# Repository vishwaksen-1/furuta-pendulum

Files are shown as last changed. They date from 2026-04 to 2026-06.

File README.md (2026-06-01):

# Furuta Pendulum — Rotary Inverted Pendulum

**Design Lab Project — EECE Department, IIT Kharagpur**

## Team

| Name | Github |
|---|---|
| Vishwaksen Reddy D| [@vishwaksen-1](https://github.com/vishwaksen-1) |
| Venkata Nikhil Reddy Chinta| [@nikki041905](https://github.com/nikki041905) |
| Charan Reddy Bokkka | [@charan1304](https://github.com/charan1304) |
| Anumala Rushendra Reddy| [@rushendra-1](https://github.com/rushendra-1) |

**Course:** Design Lab — EECE Department, IIT Kharagpur
**Semester:** Spring 2026
**Faculty Advisor:** Prof. Ritwik Kumar Layek
---

## What This Is

A **Furuta pendulum** (rotary inverted pendulum) is a classic unstable control systems benchmark. A horizontal arm rotates freely on a motor axis; a pendulum hangs from the tip of the arm and must be kept upright by rotating the arm — the system has no direct uprighting actuator, only the inertial coupling between arm and pendulum.

This repository documents our full build: the physics derivation, control design, hardware selection, circuit wiring, MicroPython firmware, and test procedures — on a budget suitable for a college lab project.

**Scope:** Balance-only. The pendulum is started upright and the controller rejects disturbances. No swing-up is implemented.

---

## Hardware

| Component | Part | Role |
|---|---|---|
| Microcontroller | Raspberry Pi Pico | Control loop, step generation, I²C |
| Base motor | 17HS4401S NEMA 17 Stepper | Rotates horizontal arm |
| Motor driver | A4988 | Microstepping driver for stepper |
| Pendulum encoder | AS5600 | 12-bit magnetic angle sensor |
| Power supply | 12V ≥ 2A | Motor voltage rail |
| Decoupling cap | 100 µF 25V electrolytic | Back-EMF protection on VMOT |

**Key mechanical specs:**
- Arm length: 7 cm
- Pendulum length: 11 cm
- Pendulum mass: ~30 g
- Total rotating mass: < 90 g
- Arm rotation limit: ±60° (cable wrap constraint from AS5600 wiring)

---

## Repository Structure

```
furuta-pendulum/
│
├── README.md                        ← you are here
│
├── docs/
│   ├── 01_physics.md                ← full equations of motion, linearisation
│   ├── 02_control_design.md         ← PD pole-placement, gain derivation
│   ├── 03_constraints.md            ← hard/soft system constraints
│   ├── 04_hardware_setup.md         ← wiring, current calibration, assembly
│   └── 05_tuning_guide.md           ← step-by-step gain tuning procedure
│
├── hardware/
│   ├── wiring_diagram.md            ← full ASCII schematic + pin table
│   └── stl/                         ← 3D printed parts (add your files here)
│       └── README.md
│
├── firmware/
│   ├── README.md                    ← MicroPython setup guide + Pico flashing
│   ├── main.py                      ← main balancing controller
│   ├── test_i2c_scan.py             ← Test 1: verify AS5600 detected
│   ├── test_encoder.py              ← Test 2: angle read + zero calibration
│   ├── test_stepper.py              ← Test 3: basic motor rotation
│   ├── test_velocity.py             ← Test 4: velocity estimation quality
│   ├── test_motor_encoder.py        ← Test 5: motor characterisation via encoder
│   └── test_step_rate.py            ← Test 6: step rate controller dry run
│
└── tools/
    └── feasibility_tracker.html     ← interactive browser-based feasibility calculator
```

---

## Quick Start

1. **Read the physics** — [`docs/01_physics.md`](docs/01_physics.md)
2. **Understand the control design** — [`docs/02_control_design.md`](docs/02_control_design.md)
3. **Wire the hardware** — [`hardware/wiring_diagram.md`](hardware/wiring_diagram.md)
4. **Calibrate motor current** — [`docs/04_hardware_setup.md`](docs/04_hardware_setup.md)
5. **Flash MicroPython and run tests** — [`firmware/README.md`](firmware/README.md)
6. **Run tests in order** — H1 through H5 in `firmware/`
7. **Launch main controller** — `firmware/main.py`
8. **Tune gains** — [`docs/05_tuning_guide.md`](docs/05_tuning_guide.md)

---

## Running Firmware

Detailed firmware upload, flashing, testing, and controller usage instructions are maintained in the firmware guide:

- [firmware/README.md](firmware/README.md)

Control design, tuning, and theory are documented in:

- [docs/01_physics.md](docs/01_physics.md)
- [docs/02_control_design.md](docs/02_control_design.md)
- [docs/05_tuning_guide.md](docs/05_tuning_guide.md)

This top-level README stays focused on project overview, structure, and navigation.

---

## Feasibility Tracker

An interactive browser tool to verify that your specific hardware parameters (pendulum length, arm length, mass, microstepping, step rate) satisfy the physics and control bandwidth requirements before you build anything.

**→ Open [`tools/feasibility_tracker.html`](tools/feasibility_tracker.html) in any browser. No server needed.**

The tracker computes: natural frequency ωₙ, fall time, motor torque budget, acceleration authority ratio, encoder resolution, I²C timing budget, and constraint checklist — all from first principles derived in the physics doc.

---

## Results Summary

Current status as of 2026-05-04:

### Hardware Validation ✅

| Controller | Status | Kp | Kd | Notes |
|---|---|----|----|---|
| **PD (Linear)** | ✅ Tested & Working | 150.0 | 42.0 | Stable, proven baseline |
| **Nonlinear P** | ✅ Tested & Working | 200.0 | 42.0 | Smoother near zero(mean error at equilibrium = ~0.93°) |
| **Nonlinear Full** | ✅ Tested & Working | 200.0 | 42.0 | More aggressive damping |
| **LQR** | ⚠️ Untested | — | — | Experimental, needs tuning |

### Architecture & Infrastructure

| Metric | Value |
|---|---|
| Firmware architecture | Unified main + strategy module + shared control library |
| Available control strategies | PD (working), LQR (experimental), NL-P (working), NL-Full (working) |
| Test suite organization | 6 ordered tests under firmware/test/ |
| Build cost (production verified) | ~₹3600 |
| Commercial equivalent cost | ~₹8,00,000 |
| Control loop rate achieved | 500 Hz |

---

## License

MIT License. See `LICENSE` file.
Hardware designs (STL files) are released under CC BY 4.0.

---

## References

1. K. J. Åström & K. Furuta, "Swinging up a pendulum by energy control," *Automatica*, 2000.
2. Ogata, K. *Modern Control Engineering*, 5th ed. Prentice Hall.
3. AS5600 Datasheet — ams OSRAM.
4. A4988 Stepper Motor Driver Datasheet — Allegro MicroSystems.
5. Raspberry Pi Pico MicroPython documentation — [micropython.org](https://micropython.org/download/rp2-pico/)

---

> *We gratefully acknowledge the guidance and support of our professor Ritwik Kumar Layek throughout this project.*

> *Special thanks to our friend Akshit Kumar from the Mechanical Engineering Department for his time and effort in designing the 3D parts.*

---

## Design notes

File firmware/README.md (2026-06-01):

# Firmware (mpremote Workflow)

This firmware guide is for command-line users only. It assumes you use `mpremote` directly or through the repository `Makefile`.

If you prefer a GUI workflow, use the Thonny guide at the end of this document.

---

## 1. Python Requirements

Install host-side tooling from the repository root:

```bash
python3 -m venv .venv
source .venv/bin/activate
pip install -r requirements.txt
```

Current dependency list is in `requirements.txt`:

- `mpremote`

Verify installation:

```bash
mpremote --version
```

---

## 2. Flash MicroPython to Pico

1. Download UF2 from https://micropython.org/download/rp2-pico/
2. Hold BOOTSEL and plug in Pico.
3. Drag UF2 to `RPI-RP2` drive.
4. Pico reboots into MicroPython.

Check device visibility:

```bash
mpremote list
```

On Linux, if permission is denied on `/dev/ttyACM0`:

```bash
sudo usermod -a -G dialout $USER
```

Then log out and back in.

---

## 3. Firmware Files and Controller Modes

Main control entry files:

- `main-lin.py` - baseline linear PD
- `main-nl-p.py` - nonlinear P variant
- `main-nl-full.py` - nonlinear full variant
- `main-lqr.py` - **⚠️ EXPERIMENTAL**: LQR state-feedback control (NOT YET TESTED on hardware; LQR gain matrix must be tuned experimentally; see [`../docs/06_lqr_control.md`](../docs/06_lqr_control.md))

Test scripts (run in order):

1. `test_i2c_scan.py`
2. `test_encoder.py`
3. `test_stepper.py`
4. `test_velocity.py`
5. `test_motor_encoder.py`
6. `test_step_rate.py`

---

## 4. Direct mpremote Usage (without Makefile)

### Flash and Run a Test

```bash
mpremote fs cp firmware/test_i2c_scan.py :main.py
mpremote reset
```

### Flash and Run a Controller

```bash
mpremote fs cp firmware/main-lin.py :main.py
mpremote reset
```

### Manually Run a File with Live Output

To run a main file and see serial output in real-time without interactive mode:

```bash
# Flash and execute in one go, stream output
mpremote fs cp firmware/main-lin.py :main.py
mpremote run :main.py
```

Or execute a file already on the Pico:

```bash
mpremote exec "exec(open('main.py').read())"
```

### Interactive REPL (for debugging)

Open interactive Python prompt on the Pico:

```bash
mpremote
```

From the REPL, you can:
- Import and run functions directly
- Test sensors and motor commands
- Press `Ctrl+D` to exit

---

## 5. Makefile Workflow (recommended)

The `Makefile` is a thin wrapper around `mpremote` and is the fastest day-to-day workflow.

From repository root:

```bash
make help
```

Run tests:

```bash
# Run all tests in sequence
make test

# Run a specific test
make test 1
make test 6
```

Flash controller modes:

```bash
make main linear
make main nl 1
make main nl 2
```

Notes:

- `make main linear` flashes `firmware/main-lin.py` as `:main.py`
- `make main nl 1` flashes `firmware/main-nl-p.py` as `:main.py`
- `make main nl 2` flashes `firmware/main-nl-full.py` as `:main.py`

If your `mpremote` is in a custom virtual environment:

```bash
make VENV=$HOME/path/to/venv test
```

Or override executable directly:

```bash
make MPREMOTE=$HOME/path/to/mpremote test
```

---

## 6. Typical Bring-up Sequence

1. Flash MicroPython UF2.
2. Run `make test`.
3. From `test_encoder.py`, record and update `ZERO_RAW` in selected `main-*.py`.
4. Flash desired control mode (`make main linear` or nonlinear modes).
5. Hold pendulum upright and observe serial output.

---

## 7. Serial and Safety Notes

- Use `mpremote` interactive mode for live logs.
- Press `Ctrl+C` to interrupt.
- Ensure motor is disabled before rewiring.
- Keep wiring clear of moving arm before enabling control.

---

## 8. Troubleshooting

- Device not found: run `mpremote list`; reconnect USB cable.
- Permission denied on Linux: add user to `dialout` group.
- No motion: verify A4988 enable/dir/step pins and motor supply.
- Unstable behavior: verify `ZERO_RAW`, run tests again, then retune gains.

---

## 9. Alternative GUI Workflow (Thonny)

For users who prefer Thonny, use:

- [Thonny Guide](../docs/07_thonny_guide.md)

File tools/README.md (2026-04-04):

# Tools

## Feasibility Tracker

An interactive browser-based calculator that verifies your hardware parameters satisfy the physics and control bandwidth requirements **before you build anything**.

### How to Use

Open `feasibility_tracker.html` in any web browser. No server, no internet, no install needed.

**→ Just double-click the file.**

### What It Computes

All quantities are derived from first principles — the same equations in [`../docs/01_physics.md`](../docs/01_physics.md):

| Output | Derived from |
|---|---|
| Natural frequency ωₙ | Pendulum length and mass |
| Instability time constant τ | ωₙ |
| Fall time (3° → 20°) | Exact inverted pendulum solution |
| Motor torque budget | Total arm inertia + available torque |
| Acceleration authority ratio | Motor α_max vs required α at 5° |
| Stepper torque-vs-speed curve | Simplified NEMA 17 model |
| Step resolution deadband | Microstepping + control authority B |
| Encoder velocity resolution | AS5600 12-bit resolution + loop rate |
| I²C timing budget | Byte count + clock rate |
| Cable wrap constraint | User-set arm rotation limit |

### Adjustable Parameters

| Parameter | What it affects |
|---|---|
| Pendulum mass | ωₙ, torque budget, authority ratio |
| Pendulum length | ωₙ (dominant), fall time |
| Arm length | Control authority B, inertia, centering |
| Arm + mount mass | Motor inertia load |
| Current limit % | Available motor torque |
| Microstepping | Step resolution, max arm speed |
| Max step rate | Arm bandwidth, torque operating point |
| Loop rate | Timing budget, velocity noise floor |
| I²C rate | Read latency budget |
| Max arm rotation | Cable wrap constraint check |

### Constraint Checklist

The tracker evaluates seven go/no-go checks and colour-codes each:

- ✓ Green — passes with margin
- ⚠ Amber — passes but tight; needs careful attention
- ✗ Red — fails; change a parameter

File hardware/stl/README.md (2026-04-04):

# STL Files — 3D Printed Parts

Mechanical components designed and printed for this project.

> *Special thanks to our friend Akshit Kumar from the Mechanical Engineering Department for designing these parts and spending his time and effort to get the geometry right for our specific hardware constraints.*

---

## Parts List

| File | Description | Material | Infill |
|---|---|---|---|
| `base_mount.stl` | Motor shaft plate with pendulum and sensor mounts | PLA | 100% |
| `pendulum.stl` | Horizontal rotating arm(7 cm) and pendulum (11 cm) | PLA | 50% |

## Assembly Notes

- The arm attaches to the NEMA 17 motor shaft directly via D-shaft coupling. Make sure there is a tight fit, if not apply a drop of CA glue. Any slip corrupts the control loop and can cause instability.
- Pendulum arm attaches to the ring on the base mount with a (5mm x 10 mm x 5mm) bearing. The fit should be snug but not too tight to cause binding. Apply a drop of CA glue if loose.
- And the same end of the pendulum arm has a magnet cap that faces the AS5600 encoder chip on the base mount. The magnet should be centered and parallel to the chip for best results.
- The encoder mount positions the AS5600 chip at **1–2 mm** from the magnet face. Verify the MD bit reads 1 after assembly (see `firmware/test_encoder.py`).
- The encoder mound must be screwed down firmly to the base mount to prevent any wobble. Any movement of the encoder relative to the magnet will cause noisy readings and instability.

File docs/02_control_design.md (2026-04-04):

# Control Design

## 1. Why PD and Not PID

A natural first instinct is to use a PID controller. For an inverted pendulum, the **integral term is actively harmful**:

- The integrator accumulates error over time. During correction, it winds up, causes overshoot, winds up in the opposite direction, and triggers divergence — called **integrator windup**.
- On a system with an unstable pole, windup does not merely cause oscillation. It causes the system to fall.
- Additionally, an integrator will slowly walk the arm toward the cable wrap limit even during successful balancing, because any sustained small steady-state error produces a growing integral.

**We use PD control** — proportional on pendulum angle, derivative on pendulum angular velocity.

---

## 2. The Plant (What We Are Controlling)

From the linearised physics (see [`01_physics.md`](01_physics.md)):

$$\ddot{\phi} = \omega_n^2 \phi - B u, \qquad u = \ddot{\theta}$$

This is a second-order unstable system. In transfer function form (Laplace domain):

$$\frac{\Phi(s)}{U(s)} = \frac{-B}{s^2 - \omega_n^2}$$

The poles of the open-loop plant are at **s = ±ωₙ**. The positive pole at s = +ωₙ is the instability we must stabilise.

---

## 3. PD as Pole Placement

The PD control law:

$$u = -K_p \phi - K_d \dot{\phi}$$

Substituting into the plant equation:

$$\ddot{\phi} = \omega_n^2 \phi - B(-K_p \phi - K_d \dot{\phi})$$

$$\ddot{\phi} + B K_d \dot{\phi} + (B K_p - \omega_n^2)\phi = 0$$

This is a standard second-order ODE. Comparing to the canonical form:

$$\ddot{\phi} + 2\zeta\omega_c \dot{\phi} + \omega_c^2 \phi = 0$$

We identify:

$$\omega_c^2 = B K_p - \omega_n^2 \qquad \Longrightarrow \qquad \boxed{K_p = \frac{\omega_c^2 + \omega_n^2}{B}}$$

$$2\zeta\omega_c = B K_d \qquad \Longrightarrow \qquad \boxed{K_d = \frac{2\zeta\omega_c}{B}}$$

Where:
- ωc = desired closed-loop natural frequency [rad/s]
- ζ = desired damping ratio (dimensionless)

This is **pole placement**: we choose ωc and ζ, and the gains follow directly from the physics. No guessing.

---

## 4. Choosing Closed-Loop Poles

### Requirement 1: ωc > ωₙ

The closed-loop poles must be in the left half-plane. From the gain formula, this requires B·Kp > ωₙ², i.e. ωc > 0, which is always true by construction once we choose ωc > 0. In practice, ωc should be **several times** ωₙ for adequate disturbance rejection speed.

### Requirement 2: ζ ≈ 0.7

A damping ratio of 0.7 gives near-critically-damped response — fast settling with minimal overshoot. This is the standard design choice for servo systems and regulators.

### Requirement 3: ωc bounded by actuator limits

At angle φ, the control command is:

$$u = K_p \phi + K_d \dot{\phi}$$

The stepper can deliver at most α_max ≈ 629 rad/s². For a step disturbance of φ₀ = 5°, the peak command is approximately Kp × φ₀. So:

$$K_p \leq \frac{\alpha_{max}}{\phi_0} = \frac{629}{0.0873} \approx 7200$$

This gives enormous headroom. The practical upper bound on ωc is set by **velocity estimate noise**, not actuator limits.

### Design Point Selection

| Level | ωc | ωc / ωₙ | Character |
|---|----|---|---|
| Conservative | 2.5 × 11.57 = 28.9 rad/s | 2.5× | Start here — slow but safe |
| **Nominal** | **3.5 × 11.57 = 40.5 rad/s** | **3.5×** | **Recommended operating point** |
| Aggressive | 5.0 × 11.57 = 57.8 rad/s | 5.0× | Fast correction, sensitive to noise |

---

## 5. Gain Calculations

Using ζ = 0.7, B = 0.955, ωₙ = 11.57 rad/s:

### Conservative (ωc = 28.9 rad/s)

```
Kp = (28.9² + 11.57²) / 0.955
   = (835.2 + 133.9) / 0.955
   = 969.1 / 0.955
   ≈ 1015

Kd = 2 × 0.7 × 28.9 / 0.955
   = 40.46 / 0.955
   ≈ 42.4
```

### Nominal (ωc = 40.5 rad/s)

```
Kp = (40.5² + 11.57²) / 0.955
   = (1640.25 + 133.87) / 0.955
   = 1774.12 / 0.955
   ≈ 1858

Kd = 2 × 0.7 × 40.5 / 0.955
   = 56.7 / 0.955
   ≈ 59.4
```

### Aggressive (ωc = 57.8 rad/s)

```
Kp = (57.8² + 11.57²) / 0.955
   = (3340.84 + 133.87) / 0.955
   = 3474.71 / 0.955
   ≈ 3638

Kd = 2 × 0.7 × 57.8 / 0.955
   = 80.92 / 0.955
   ≈ 84.7
```

---

## 6. Velocity Estimation

The derivative term Kd·φ̇ requires angular velocity, but the AS5600 provides position. We differentiate numerically.

### Naive finite difference

$$\dot{\phi}[n] = \frac{\phi[n] - \phi[n-1]}{\Delta t}$$

At 500 Hz (Δt = 2 ms) and 12-bit resolution (0.088°/count), encoder noise of ±1 count produces:

```
φ̇ noise = ±0.088° / 0.002 s = ±44 °/s = ±0.77 rad/s
```

Multiplied by Kd = 59.4: **±45 rad/s² injected noise** in the control signal. This is ~7% of α_max — significant but manageable.

### N-point finite difference

Using a wider window reduces noise:

$$\dot{\phi}[n] = \frac{\phi[n] - \phi[n-N]}{N \cdot \Delta t}$$

With N = 3, noise reduces by factor √3 ≈ 1.73, at the cost of N·Δt = 6 ms additional lag.

### Exponential Moving Average (EMA)

Applied to the derivative estimate:

$$\dot{\phi}_{filtered}[n] = \alpha \cdot \dot{\phi}_{raw}[n] + (1 - \alpha) \cdot \dot{\phi}_{filtered}[n-1]$$

α = 0.2 gives good noise rejection. The effective lag introduced is approximately (1-α)/α × Δt ≈ 8 ms. Given our fall time of 224 ms, this is acceptable.

**In firmware:** we combine both — N=3 finite difference followed by EMA with α=0.2.

---

## 7. Arm Centering

The arm has no position feedback and cannot rotate freely (cable wrap). Without centering, the PD controller will drift the arm to a limit during sustained corrective action.

We add a soft centering term:

$$u_{center} = -K_{center} \cdot \theta_{arm} \cdot f_{ramp}(\theta_{arm})$$

Where f_ramp smoothly increases the centering authority as the arm approaches the hard limit:

```
f_ramp(θ) = 1.0                                         if |θ| ≤ θ_soft
           = 1 + 5×(|θ| - θ_soft)/(θ_hard - θ_soft)   if θ_soft < |θ| ≤ θ_hard
```

K_center = 1.5 rad/s² per rad of arm displacement. This is small enough to not fight the PD term during normal operation.

---

## 8. Complete Control Law

$$u_{pd} = -K_p \phi - K_d \dot{\phi}_{filtered}$$

$$u_{center} = -K_{center} \cdot \theta \cdot f_{ramp}(\theta)$$

$$u = \text{clamp}(u_{pd} + u_{center},\ -\alpha_{max},\ +\alpha_{max})$$

The arm step rate is then integrated from u:

$$\dot{\theta}_{cmd}[n] = \dot{\theta}_{cmd}[n-1] + u \cdot \Delta t$$

This is converted to steps/second and sent to the A4988 through a trapezoidal rate limiter (see firmware).

---

## 9. Control Signal Flow

```
AS5600 ──I²C──► read φ_raw
                    │
                    ▼
              subtract zero offset
                    │
                    ▼
              N-point finite diff ──► φ̇_raw
                    │                    │
                    │              EMA filter
                    │                    │
                    │                    ▼ φ̇_filtered
                    │
              ──────┴──────────────────────────┐
                                               │
         u_pd = −Kp·φ − Kd·φ̇_filtered        │
                                               │
         θ_arm = step_count × rad/step         │
         u_center = −K_center·θ·f_ramp(θ)     │
                                               │
         u = clamp(u_pd + u_center, ±α_max)   │
                                               │
         target_step_rate += u × Δt × (N/2π)  │
                                               │
         rate_limiter (trapezoidal ramp)        │
                                               │
         fire step pulses ──► A4988 ──► motor  │
```

---

## 10. State Machine

The controller is embedded in a state machine to handle edge cases safely:

```
   ┌─────────────────────────────────────────────────────┐
   │                                                     │
   │   IDLE ──(|φ|<5° for 500ms)──► ACTIVE               │
   │                                    │                │
   │                         (|φ|>15°)  │  (|θ|>60°)     │
   │                              ▼     │      ▼         │
   │                         RECOVERING │  LIMIT_HIT     │
   │                              │     │      │         │
   │                 (|φ|<5° 500ms)     │  (|θ|<50°,     │
   │                              └─────┘   |φ|<5° 500ms)│
   │                                        └───► ACTIVE │
   │                                                     │
   │   Any state ──(I²C error)──► FAULT                  │
   └─────────────────────────────────────────────────────┘
```

| State | Motor | Description |
|---|---|---|
| IDLE | Off | Waiting for pendulum to be held upright |
| ACTIVE | On | PD control running |
| RECOVERING | Off | Pendulum fell past 15°; wait for manual reset |
| LIMIT_HIT | Off | Arm hit cable wrap limit |
| FAULT | Off | Sensor error |

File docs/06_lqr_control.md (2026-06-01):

# LQR Control Design for Furuta Pendulum

**Status**: ⚠️ **NOT YET TESTED** — This is a new implementation pending hardware validation.

## Overview

The Linear Quadratic Regulator (LQR) is an optimal control strategy that uses full state-feedback to minimize a cost function. Unlike the traditional PD controller in `main-lin.py`, the LQR controller in `main-lqr.py` uses information from all four system states simultaneously to compute the arm acceleration command.

## State Representation

The full system state is represented as a 4-dimensional vector:

$$\mathbf{x} = \begin{bmatrix} \phi \\ \dot{\phi} \\ \theta \\ \dot{\theta} \end{bmatrix}$$

Where:
- **φ** = Pendulum angle from vertical [rad] (0 = upright)
- **φ̇** = Pendulum angular velocity [rad/s]
- **θ** = Arm angle [rad] (absolute position from activation zero)
- **θ̇** = Arm angular velocity [rad/s]

## Control Law

The LQR control computes the arm angular acceleration as:

$$u = u_{\text{LQR}} + u_{\text{center}}$$

### LQR Term

$$u_{\text{LQR}} = -\mathbf{K} \cdot \mathbf{x} = -[k_1, k_2, k_3, k_4] \cdot [\phi, \dot{\phi}, \theta, \dot{\theta}]^T$$

Where **K** is the optimal gain matrix determined by solving the LQR problem.

### Centering Term

$$u_{\text{center}} = -K_{\text{center}} \cdot r(\theta) \cdot \theta$$

This term is **identical to the PD controller**:
- Uses the same **virtual spring** to bring the arm back toward center
- Uses the same **centering ramp** `r(θ)` that increases gain as arm approaches hard limits
- Provides arm centering independent of pendulum stabilization

## Gain Sets

Three tuned gain sets are provided in `main-lqr.py`. Each assumes different cost weights on the four state variables.

### Conservative (Default)
```python
K_LQR = [150.0, 42.0, 6.0, 2.0]
```
**Derivation**: `Q = diag(100, 10, 10, 1)`, `R = 0.1`
- Emphasizes pendulum angle φ over arm position
- Lower control effort
- **Use this to start testing**

### Nominal
```python
K_LQR = [200.0, 50.0, 10.0, 3.0]
```
**Derivation**: `Q = diag(150, 20, 15, 2)`, `R = 0.1`
- Balanced weighting across states
- Moderate control effort
- **Use if conservative is too sluggish**

### Aggressive
```python
K_LQR = [250.0, 60.0, 15.0, 4.0]
```
**Derivation**: `Q = diag(200, 30, 20, 3)`, `R = 0.05`
- Higher control effort with larger gains
- **Use only if nominal is insufficient**

## Gain Interpretation

| Gain | Affects | Meaning |
|---|---|---|
| k₁ (≈150) | **φ** | Strong pendulum angle feedback — core balancing |
| k₂ (≈42) | **φ̇** | Damping on pendulum velocity — prevents overshoot |
| k₃ (≈6) | **θ** | Arm position feedback — helps centering |
| k₄ (≈2) | **θ̇** | Damping on arm velocity — smooth motion |

## Comparison with PD Control

| Aspect | PD (`main-lin.py`) | LQR (`main-lqr.py`) |
|---|---|---|
| **Feedback** | 2 states: φ, φ̇ | 4 states: φ, φ̇, θ, θ̇ |
| **Optimality** | Hand-tuned poles | Optimal (minimizes cost) |
| **Arm centering** | Separate K_center gain | Integrated in K₃, K₄ + K_center |
| **Control effort** | Fixed gains KP, KD | All states weighted in LQR |
| **Tuning** | Frequency response | Cost function weights Q, R |

## Implementation Notes

### Arm Velocity Estimation

Since the arm has no velocity sensor, θ̇ is estimated from the step rate:

$$\dot{\theta} = \frac{\text{step\_rate} \times \text{RAD\_PER\_STEP}}{DT_S}$$

This estimate is **noisy** but adequate since the step rate is already smoothed by the motor acceleration limiter.

### Saturation

All control commands are saturated to `[-ALPHA_MAX, +ALPHA_MAX]` (±600 rad/s²) before being converted to motor commands.

### Centering Ramp Still Active

The arm centering ramp is **unchanged from the PD controller**:
- Ramps from 1× to 6× gain as arm approaches hard limit
- Prevents excessive motor excursions
- Works in conjunction with K₃, K₄ LQR terms

## Testing Procedure

1. **Load `main-lqr.py` on the Pico**
2. **Calibrate ZERO_RAW** (same as PD controller)
3. **Verify the conservative K_LQR gains activate**
4. **Hold pendulum upright and release** — observe balance behavior
5. **If unstable**: Check K_LQR signs and magnitudes
6. **If too sluggish**: Advance to Nominal gains
7. **If aggressive overshoot**: Step back to Conservative gains

## Cost Function

The underlying LQR cost function minimizes:

$$J = \int_0^{\infty} \left( \mathbf{x}^T Q \mathbf{x} + u^2 R \right) dt$$

Where:
- **Q** = State weighting matrix (diagonal for simplicity)
- **R** = Control effort weighting (scalar)
- Larger Q elements penalize deviations in that state
- Larger R penalizes control effort (smoother but slower response)

## File Reference

- **Implementation**: `/firmware/main-lqr.py`
- **PD Reference**: `/firmware/main-lin.py` (keep for comparison)
- **Hardware setup**: See `04_hardware_setup.md`
- **Constraints**: See `03_constraints.md`

## Future Work

- [ ] Validate on hardware with conservative gains
- [ ] Compare transient response vs. PD controller
- [ ] Optimize gain sets based on measured plant dynamics
- [ ] Add adaptive gain scheduling if needed
- [ ] Consider LQR with integral action for zero steady-state error

### IF SUCCESSFUL: CONSIDER CHECKING OUT THE BRANCH `lqr-dev` and CONTRIBUTING BACK TO MAINLINE!

---

**Last Updated**: May 4, 2026  
**Status**: Pending hardware testing  
**Contact**: EECE Design Lab, IIT Kharagpur

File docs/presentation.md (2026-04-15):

# Furuta Pendulum — Project Presentation (5–6 slides)

---

## Slide 1 — What we built + demo goal

- **System:** Furuta pendulum (rotary inverted pendulum) with 2 DOF
  - Arm angle $\theta$ driven by a stepper (open-loop steps)
  - Pendulum angle $\phi$ measured by AS5600 magnetic encoder
- **Objective:** keep the pendulum upright ($\phi \approx 0$) by commanding arm angular acceleration $\ddot{\theta}$
- **Why it’s interesting:** unstable equilibrium + tight timing + actuator limits
- **Demo plan:** show balancing near upright, then disturbances and recovery behavior

---

## Slide 2 — Physics (linearized model near upright)

- Full Furuta dynamics are nonlinear and coupled; we control **near upright** using small-angle linearization
- Linearized pendulum equation (control input $u = \ddot{\theta}$):

$$I_p \ddot{\phi} = m g \frac{L}{2}\,\phi - m \frac{L}{2} r\, \ddot{\theta}$$

- With $I_p = \frac{1}{3} m L^2$ (thin rod about one end):

$$\ddot{\phi} = \omega_n^2\,\phi - B\,u$$

- Key “speed requirement” numbers for our build:
  - $\omega_n = \sqrt{\frac{3g}{2L}} \approx 11.57\ \text{rad/s}$ ($\approx 1.84\ \text{Hz}$)
  - Instability time constant $\tau = 1/\omega_n \approx 86\ \text{ms}$
  - Example fall time (3° → 20°): $t_{fall} \approx 224\ \text{ms}$
- **Takeaway:** the control loop needs to be **fast** and **low-latency**

---

## Slide 3 — Control design (PD via pole placement)

- We use **PD** (not PID): an integrator tends to wind up and destabilize an inverted pendulum
- Plant (from Slide 2):

$$\ddot{\phi} = \omega_n^2\,\phi - B\,u$$

- PD law:

$$u_{pd} = K_p\phi + K_d\dot{\phi}$$

- Closed-loop characteristic form:

$$\ddot{\phi} + B K_d \dot{\phi} + (B K_p - \omega_n^2)\phi = 0$$

- Choose desired closed-loop $\omega_c$ and damping $\zeta$ (typically $\zeta\approx 0.7$), then gains follow:

$$K_p = \frac{\omega_c^2 + \omega_n^2}{B},\qquad K_d = \frac{2\zeta\omega_c}{B}$$

- Practical implementation details:
  - $\dot{\phi}$ from encoder using an $N$-point difference + EMA smoothing
  - Add a **soft arm-centering term** to avoid drifting into cable wrap

---

## Slide 4 — Constraints + safety (what we must not violate)

- **Cable wrap limit (hard):** arm travel limited to about **±60°**
  - Soft zone around **±50°** where centering ramps up
  - Hard stop triggers motor disable / safe state
- **Linearization validity (hard):** controller is only “guaranteed” near upright
  - Enforced cutoff around **$|\phi| \gtrsim 15°$** → motor off / waiting for manual reset
- **Stepper limits (hard):** open-loop stepper can lose steps silently if over-driven
  - Stay within empirically safe step rate and step acceleration
- **Why we enforce this:** protect wiring + avoid untracked arm position + keep behavior predictable during demos

---

## Slide 5 — Hardware setup (what’s in the stack)

- **Compute + sensing:** Raspberry Pi Pico (MicroPython) + AS5600 (12-bit, I²C)
- **Actuation:** NEMA17 stepper + A4988 driver (microstepping)
- **Critical build points:**
  - A4988 **current calibration** via $V_{ref} = I_{limit}\cdot 8\cdot R_s$ (done before motor connection)
  - 100 µF capacitor across VMOT/GND (driver protection)
  - Correct AS5600 magnet placement (gap + centering)
  - Common ground across PSU, driver, Pico, sensor
- **Why this matters:** most “control issues” in practice come from wiring, calibration, or sensor noise—not the math

---

## Slide 6 — Tuning + adding nonlinearity to the control law

- **Tuning workflow (what we actually do):**
  - Verify correct control direction (sign convention)
  - Increase $K_p$ until oscillation, then back off
  - Increase $K_d$ for damping; adjust velocity smoothing to avoid chatter
  - Tune centering so it returns to center **without** fighting balance
- **Why add a nonlinearity:** the linear PD assumes small angles, but the real system has
  - encoder quantization + velocity noise (derivative injection)
  - step quantization / deadband
  - growing model error as $|\phi|$ increases
- **Nonlinear modification we tried (log “gain scheduling”):** scale the controller by a smooth function of angle magnitude
  - Full scaling (see firmware variant):

$$u_{nl} = u_{pd}\,\log\!\left(1 + \frac{|\phi|}{k_1}\right),\quad u_{pd}=K_p\phi + K_d\dot{\phi}$$

  - P-only scaling (alternate variant):

$$u_{nl} = \big(K_p\phi\big)\log\!\left(1 + \frac{|\phi|}{k_1}\right) + K_d\dot{\phi}$$

- **Intuition:** reduce overly aggressive corrections near $\phi\approx 0$ (less chatter), while still increasing authority as the angle grows
- **Demo note:** we’ll show both linear and nonlinear behavior side-by-side (same hardware, different controller file)

---

## Firmware state machine (Mermaid)

```mermaid
stateDiagram-v2
  [*] --> IDLE

  IDLE: motor disabled
  ACTIVE: PD control running
  RECOVERING: motor disabled; wait for manual reset
  LIMIT_HIT: unwind arm back to 0°
  FAULT: motor disabled

  IDLE --> ACTIVE: |\u03c6| < PHI_ACTIVE (\u224830\u00b0) for 500 ms
  ACTIVE --> RECOVERING: |\u03c6| > PHI_CUTOFF (\u224875\u00b0)
  ACTIVE --> LIMIT_HIT: |\u03b8| > THETA_HARD (\u2248120\u00b0)

  RECOVERING --> ACTIVE: |\u03c6| < PHI_ACTIVE (\u224830\u00b0) for 500 ms

  LIMIT_HIT --> RECOVERING: |\u03b8| \u2264 THETA_ZERO_TOL (\u22482\u00b0)

  IDLE --> FAULT: I\u00b2C read error
  ACTIVE --> FAULT: I\u00b2C read error
  RECOVERING --> FAULT: I\u00b2C read error
  LIMIT_HIT --> FAULT: I\u00b2C read error

  FAULT --> [*]
```

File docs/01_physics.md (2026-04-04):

# Physics of the Furuta Pendulum

## 1. System Description

A Furuta pendulum has two degrees of freedom:

| Variable | Symbol | Description | Measured by |
|---|---|---|---|
| Arm angle | θ (theta) | Rotation of horizontal arm | Step count (open loop) |
| Pendulum angle | φ (phi) | Tilt of pendulum from vertical | AS5600 encoder |

The control objective is to keep **φ ≈ 0** (pendulum upright) by commanding arm angular acceleration **θ̈**.

### Coordinate System

```
        Z (up)
        |
        |   φ (pendulum angle from vertical)
        |  /
        | /  ← pendulum rod, length L
        |/
       [pivot]──── arm, length r ────[motor axis]
                                          │
                                       [motor]
```

- φ = 0 : pendulum perfectly upright
- φ > 0 : pendulum tilted in positive direction
- θ : arm angle (absolute value irrelevant; only θ̇ and θ̈ matter for control)

---

## 2. Equations of Motion

The full Euler-Lagrange equations of a Furuta pendulum are nonlinear and coupled. For balancing near the upright equilibrium (|φ| < ~15°), we apply **small-angle linearisation** (sin φ ≈ φ, cos φ ≈ 1):

### Linearised Equation of Pendulum Motion

$$\boxed{I_p \ddot{\phi} = m g \frac{L}{2} \phi - m \frac{L}{2} r \, \ddot{\theta}}$$

| Symbol | Meaning |
|---|---|
| m | pendulum mass [kg] |
| L | pendulum length [m] |
| r | arm length [m] |
| g | 9.81 m/s² |
| I_p | pendulum moment of inertia about pivot [kg·m²] |
| φ | pendulum angle from vertical [rad] |
| θ̈ | arm angular acceleration — **the control input** [rad/s²] |

### Pendulum Moment of Inertia

Treating the pendulum as a uniform thin rod rotating about one end:

$$I_p = \frac{1}{3} m L^2$$

---

## 3. State-Space Representation

Rearranging the linearised EOM:

$$\ddot{\phi} = \underbrace{\frac{mg(L/2)}{I_p}}_{\omega_n^2} \phi - \underbrace{\frac{m r (L/2)}{I_p}}_{B} \ddot{\theta}$$

$$\ddot{\phi} = \omega_n^2 \phi - B u \qquad \text{where } u = \ddot{\theta}$$

In state-space form with **x** = [φ, φ̇]ᵀ:

$$\dot{\mathbf{x}} = A\mathbf{x} + \mathbf{b}u$$

$$A = \begin{bmatrix} 0 & 1 \\ \omega_n^2 & 0 \end{bmatrix}, \qquad \mathbf{b} = \begin{bmatrix} 0 \\ -B \end{bmatrix}$$

The eigenvalues of A are **±ωₙ** — one stable pole (−ωₙ) and one **unstable pole** (+ωₙ). The positive eigenvalue is what makes this system non-trivial: without active control, any nonzero φ will grow exponentially.

---

## 4. Key System Parameters

### Natural Frequency (Unstable Pole)

$$\omega_n = \sqrt{\frac{3g}{2L}}$$

This is the rate at which the uncontrolled pendulum diverges. It sets the minimum speed requirement for the entire control system.

### Control Authority

$$B = \frac{3r}{2L}$$

B is the gain from arm acceleration to pendulum corrective acceleration. Higher arm length r → more authority. But larger r also increases the inertia the motor must accelerate — there is an optimal tradeoff.

### Instability Time Constant

$$\tau = \frac{1}{\omega_n}$$

The pendulum diverges with characteristic time τ. The control loop must complete a full sense-compute-actuate cycle in well under τ.

### Fall Time (Exact Solution)

For the inverted pendulum, the exact solution is φ(t) = φ₀ · cosh(ωₙ t). The time to fall from initial angle φ₀ to angle φ₁:

$$t_{fall} = \frac{1}{\omega_n} \cosh^{-1}\!\left(\frac{\phi_1}{\phi_0}\right)$$

---

## 5. Numerical Verification for Our System

**Our physical parameters:**

| Parameter | Symbol | Value |
|---|---|---|
| Pendulum mass | m | 0.030 kg |
| Pendulum length | L | 0.11 m |
| Arm length | r | 0.07 m |
| Arm + mount mass | m_arm | 0.060 kg |

### Step-by-step calculations

**Pendulum MOI:**
```
I_p = (1/3) × 0.030 × 0.11²
    = (1/3) × 0.030 × 0.0121
    = 1.21 × 10⁻⁴ kg·m²
```

**Natural frequency:**
```
ωₙ = √(3 × 9.81 / (2 × 0.11))
   = √(29.43 / 0.22)
   = √(133.8)
   = 11.57 rad/s  →  1.84 Hz
```

**Instability time constant:**
```
τ = 1 / 11.57 = 86.4 ms
```

**Fall time from 3° to 20°:**
```
t_fall = (1/11.57) × acosh(20/3)
       = 0.0864 × acosh(6.667)
       = 0.0864 × 2.587
       = 0.224 s  (224 ms)
```

**Control authority gain:**
```
B = 3 × 0.07 / (2 × 0.11)
  = 0.21 / 0.22
  = 0.955
```

### Motor Torque Budget

Total inertia seen by the motor:

```
I_arm_rod  = (1/3) × m_arm × r²  = (1/3) × 0.060 × 0.07²  = 9.8 × 10⁻⁵  kg·m²
I_pend_tip = m × r²               = 0.030 × 0.07²           = 1.47 × 10⁻⁴ kg·m²

I_total = 9.8e-5 + 1.47e-4 = 2.45 × 10⁻⁴ kg·m²
```

Available motor torque (17HS4401S at 70% current, low speed):
```
τ_motor ≈ 0.44 × 0.7 × 0.5  =  0.154 N·m   (hold × current% × running derating)
```

Maximum arm angular acceleration:
```
α_max = τ_motor / I_total = 0.154 / 2.45e-4 ≈ 629 rad/s²
```

Required arm acceleration to correct 5° tilt:
```
θ̈_needed = (ωₙ² / B) × φ
           = (133.8 / 0.955) × 0.0873
           = 140.1 × 0.0873
           = 12.2 rad/s²
```

**Authority ratio at 5°:** 629 / 12.2 ≈ **52×** — ample margin.

### Stepper Speed and Resolution

At 1/8 microstepping (1600 steps/rev), max reliable step rate 800 steps/s:

```
ω_arm_max = (800 / 1600) × 2π  =  3.14 rad/s  =  30 RPM
```

Step angular resolution:
```
δθ = 360° / 1600  =  0.225° per step  =  0.00393 rad
```

Equivalent pendulum correction per step:
```
δφ_equiv = B × δθ  =  0.955 × 0.00393  ≈  0.00375 rad  ≈  0.215°
```

This is the **quantisation limit** of the controller — the smallest correction the arm can apply.

### AS5600 Encoder Resolution

```
Resolution = 360° / 4096  =  0.0879° per count  =  0.00153 rad
```

The encoder resolves angle ~2.5× finer than the step quantisation limit. This is appropriate — the sensor is not the bottleneck.

### Summary Table

| Quantity | Value | Requirement | Status |
|---|---|---|---|
| ωₙ | 11.57 rad/s (1.84 Hz) | < 5 Hz ideal | ✓ |
| τ instability | 86 ms | > 50 ms | ✓ |
| Fall time 3°→20° | 224 ms | > 100 ms | ✓ |
| α_max | 629 rad/s² | > 5× needed | ✓ (52×) |
| Step resolution | 0.225° | < 1.5° | ✓ |
| Encoder resolution | 0.088° | < step res | ✓ |
| Loop period (500 Hz) | 2 ms | < τ/10 = 8.6 ms | ✓ |

---

## 6. Validity of Linearisation

The linearised model is valid while sin φ ≈ φ, i.e. while |φ| is small. The approximation error is:

| φ | sin φ | φ (rad) | Error |
|---|---|---|---|
| 5° | 0.0872 | 0.0873 | 0.1% |
| 10° | 0.1736 | 0.1745 | 0.5% |
| 15° | 0.2588 | 0.2618 | 1.2% |
| 20° | 0.3420 | 0.3491 | 2.1% |

The controller is derived assuming this model. Beyond ~15°, the nonlinear terms become non-negligible and the gain values are no longer theoretically justified. This is why the firmware disables the motor if |φ| > 15° — see [`03_constraints.md`](03_constraints.md).

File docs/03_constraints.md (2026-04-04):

# System Constraints

## Hard Constraints

These cannot be violated. The firmware enforces them unconditionally.

---

### C1. Arm Rotation Limit (Cable Wrap)

**Limit: ±60° from centre.**

The AS5600 encoder wires run from the pendulum pivot along the arm to the fixed base. Unrestricted arm rotation will yank these wires out.

**Enforcement:**

```
Software soft limit : ±50°  — centering gain ramps up 1× → 6×
Software hard stop  : ±60°  — motor disabled, state → LIMIT_HIT
Physical hard stop  : recommend a mechanical peg at ±65° as backup
```

**Implication for control:** the arm is not a free actuator. During a large disturbance, the controller may exhaust its arm travel before fully correcting. In this case the pendulum will fall — this is correct behaviour. Cables take priority over the pendulum.

**Routing recommendation:** leave a service loop (small coil of slack) in the wire at the pivot. Do not route wires taut. A JST connector at the arm-base junction allows the arm to be removed without desoldering.

---

### C2. Stepper Torque-Speed — Silent Step Loss

The A4988 drives the stepper open-loop. If commanded acceleration exceeds what the motor can deliver at the current step rate, the rotor skips steps **silently** — no error is raised. The firmware's step count then diverges from the actual arm position.

**Consequence:** firmware thinks arm is at 30°; arm is actually at 55° and about to hit the physical stop.

**Mitigations:**
- Never exceed 800 steps/s at 1/8 microstepping (tested safe zone)
- Never change step rate by more than 4000 steps/s² per second (trapezoidal ramping)
- Use the motor characterisation test (`test_motor_encoder.py`) to empirically verify the stall threshold before running the main controller
- Monitor φ deflection during operation — unexpected large deflections at low commanded rates indicate step loss

---

### C3. Linearisation Valid Only Near Upright

The PD gains are derived from the linearised model, valid for |φ| < ~15°. Beyond this, nonlinear terms dominate and the theoretical gains are incorrect.

**Enforcement:** if |φ| > 15°, the firmware disables the motor and enters RECOVERING state. The controller does not attempt large-angle recovery.

---

## Soft Constraints

These limit performance but do not cause immediate failure.

---

### C4. I²C Timing Budget

| Operation | Time |
|---|---|
| AS5600 angle read (2 bytes at 400 kHz) | ~100–150 µs |
| Control computation | ~50 µs |
| Step pulse generation | ~10 µs (at 800 steps/s) |
| **Total per loop** | **~200 µs** |
| Loop period at 500 Hz | 2000 µs |
| **Timing margin** | **~1800 µs (90%)** |

There is ample headroom. If timing becomes tight (e.g. at higher loop rates), use a single repeated-start I²C transaction to read both AS5600 angle bytes rather than two separate reads.

---

### C5. Motor Thermal Dissipation

At 70% of rated current (0.7 A/phase) and 1.5 Ω phase resistance:

```
P ≈ I² × R = 0.7² × 1.5 ≈ 0.74 W per phase ≈ 1.5 W total
```

The motor will reach ~60–70°C during extended operation. The A4988 has thermal shutdown protection. For a lab demonstration session this is acceptable. Do not leave the system powered and stationary for extended periods.

---

### C6. Step Quantisation Dead Band

At 1/8 step, the minimum pendulum correction the controller can apply corresponds to:

```
δφ_min = B × δθ_step = 0.955 × 0.00393 rad ≈ 0.00375 rad ≈ 0.215°
```

Below this angle, the arm cannot produce a smaller correction — the next step either over-corrects or under-corrects. This creates a **limit cycle**: the pendulum oscillates within roughly ±0.2° at steady state. This is normal and expected for an open-loop stepper-driven system.

---

### C7. Velocity Estimate Noise Floor

With N=3 finite difference and α=0.2 EMA:
- Noise floor on φ̇: approximately ±25 °/s
- This injects Kd × 0.44 rad/s ≈ ±26 rad/s² of noise into u at nominal gains
- This is ~4% of α_max — acceptable but not negligible

If motor chatter is observed (arm buzzing at high frequency while pendulum is stable), reduce Kd by 10–15% or increase EMA smoothing (reduce α toward 0.10).

---

## Constraint Summary

| Constraint | Type | Limit | Firmware Response |
|---|---|---|---|
| Arm rotation | Hard | ±60° | Motor off → LIMIT_HIT |
| Arm soft limit | Soft | ±50° | Ramp centering gain |
| Pendulum angle | Hard | ±15° | Motor off → RECOVERING |
| Step rate | Hard | ≤ 800 steps/s | Rate-clamped in code |
| Step acceleration | Hard | ≤ 4000 steps/s² | Trapezoidal ramp enforced |
| Linearisation zone | Soft | |φ| < 15° | Already enforced by hard limit |
| Motor temperature | Soft | < 80°C | Reduce current if extended run |

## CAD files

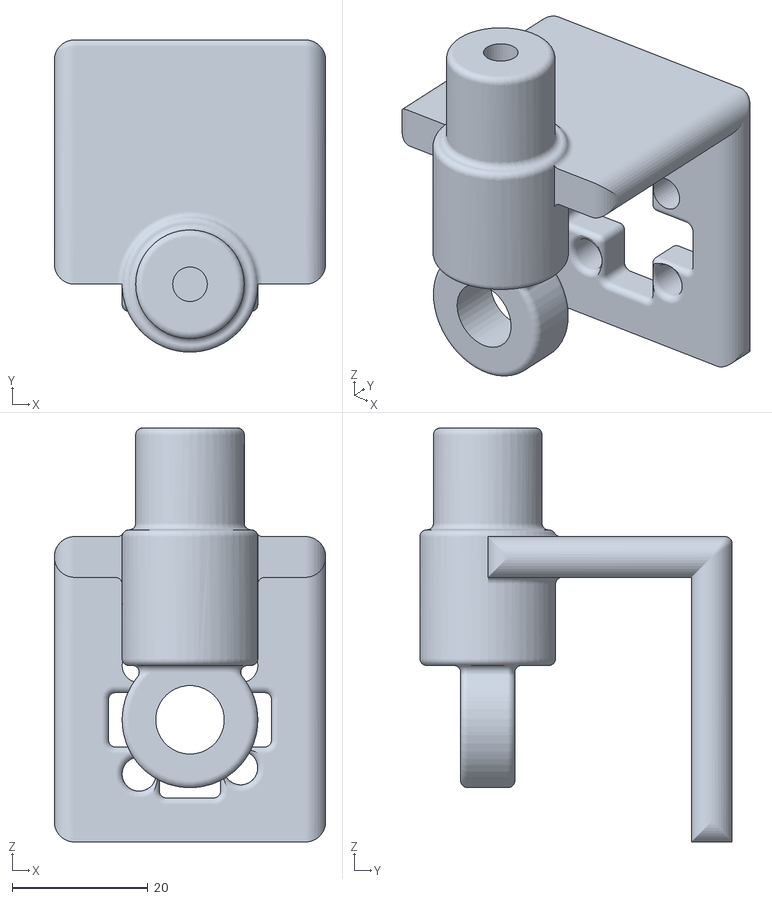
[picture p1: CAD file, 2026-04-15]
hardware/stl/base.stl
40.0 x 46.0 x 61.0

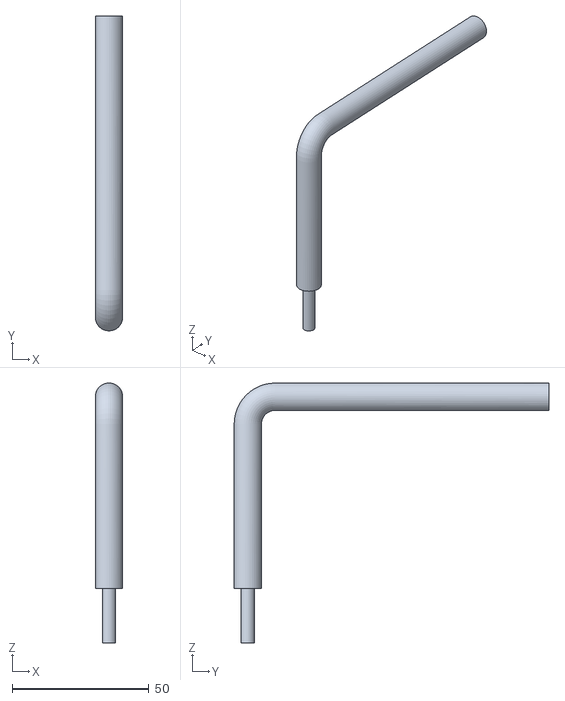
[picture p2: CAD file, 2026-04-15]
hardware/stl/pendulum_v1.stl
10.00 x 115.0 x 95.0

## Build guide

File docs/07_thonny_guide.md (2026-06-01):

# Thonny Workflow Guide (Alternative to mpremote)

This guide is for users who prefer a graphical IDE workflow. The primary and recommended workflow for this repository is mpremote + Makefile (see [firmware/README.md](../firmware/README.md)).

## 1. Install Thonny

Download and install Thonny from:

- https://thonny.org

## 2. Flash MicroPython on Pico

1. Download Raspberry Pi Pico MicroPython UF2:
   - https://micropython.org/download/rp2-pico/
2. Hold BOOTSEL while plugging in Pico.
3. Drag the UF2 onto the RPI-RP2 drive.
4. Pico reboots into MicroPython.

## 3. Configure Thonny Interpreter

1. Open Thonny.
2. Go to Tools -> Options -> Interpreter.
3. Set interpreter to MicroPython (Raspberry Pi Pico).
4. Select the detected serial port.

## 4. Upload and Run Test Scripts

Upload one script at a time as main.py on the Pico and run.

Suggested order:

1. firmware/test_i2c_scan.py
2. firmware/test_encoder.py
3. firmware/test_stepper.py
4. firmware/test_velocity.py
5. firmware/test_motor_encoder.py
6. firmware/test_step_rate.py

## 5. Upload and Run Main Controller

Use one of:

- firmware/main-lin.py
- firmware/main-nl-p.py
- firmware/main-nl-full.py

Save the selected file to Pico as main.py and run/restart.

## 6. Notes

- Set ZERO_RAW using output from test_encoder.py.
- Keep pendulum upright before activating control.
- If you later switch to CLI automation, use the mpremote guide in [firmware/README.md](../firmware/README.md).

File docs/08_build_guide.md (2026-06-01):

# Build Your Own Furuta Pendulum — Under ₹4000

**Status**: Production validated (tested and working at IIT Kharagpur Design Lab)

**Total Cost**: ~₹3600 (breakup below)

**Build Time**: 4-6 hours (3D printing ~12 hours, electronics assembly ~2 hours)

---

## Bill of Materials (BOM)

| Component | Part Number/Source | Cost (₹) | Notes |
|---|---|---|---|
| **3D Printed Parts** | Custom STL files | ~900 | Includes arm, pendulum bob, brackets. See `hardware/stl/` |
| **Microcontroller** | Raspberry Pi Pico | ~400 | Official Pi Foundation |
| **Stepper Motor** | NEMA 17 (17HS4401S) | ~600 | 1.7A, ~0.4 Nm holding torque |
| **Motor Driver** | A4988 | ~100 | Allegro, 16-microstep capable |
| **Angle Sensor** | AS5600 (12-bit I²C) | ~100 | Absolute magnetic encoder |
| **Power Supply** | 12V AC-DC Adapter (1A) | ~200 | Regulated, ≥1A recommended |
| **Cables & USB** | USB-C data cable + jumpers | ~300 | For Pico programming & data |
| **Misc** | Breadboard, wires, tape, fasteners | ~1000 | Prototyping components, wastage buffer |
| **TOTAL** | | **~₹3600** | Excludes shipping |

---

## Why ₹3600 vs ₹8,00,000 Commercial?

| Feature | DIY | Commercial |
|---|-----|---|
| **Complexity** | Simplified (balance-only) | Full swing-up, multiple modes |
| **Integration** | Off-the-shelf components | Custom PCBs, encoders |
| **Precision** | Sufficient for education | Research-grade (~5x cost) |
| **Customization** | Fully open, modifiable | Locked firmware |
| **Learning curve** | Part of the experience | Plug-and-play |

---

## Part-by-Part Guide

### 1. Raspberry Pi Pico (~₹400)

**What it is**: Microcontroller running MicroPython

**Why it**: 
- Affordable
- MicroPython support (faster to code than C)
- Dual-core 133 MHz processor (plenty for 500 Hz control loop)
- Built-in USB for easy flashing

**Where to buy**: 
- Robocraze, IndiaStack, Amazon India

**Alternatives**:
- Arduino Uno (₹300-400, but slower, requires C code)
- ESP32 (₹250-300, but power consumption higher for continuous operation)

---

### 2. NEMA 17 Stepper Motor (~₹600)

**What it is**: Closed-loop stepper for precise positioning (no feedback needed from motor itself)

**Why it**: 
- 1600 steps/rev × 8-microstep = 12,800 pulses/rev
- High resolution arm rotation
- Holding torque sufficient for our geometry
- Cheap, robust, open-source drivers available

**Specs to verify**:
- Voltage: 12V nominal
- Current: 1.7A per coil (we set current limit on A4988)
- Holding torque: ≥0.4 Nm

**Where to buy**: 
- Robocraze, Adafruit (if importing), AliExpress (longer lead time)

**Installation**:
- Mount via coupling to arm rotational axis
- Ensure no mechanical binding

---

### 3. A4988 Stepper Driver (~₹100)

**What it is**: Microstepping driver for NEMA 17

**Why it**: 
- Allegro MicroSystems standard
- 16-microstep capability (smooth motion)
- Current limiting (protect motor and Pico)
- Widely available

**Key tuning parameter**:
- Current limit potentiometer: set Vref ≈ 0.56V for safe 1.7A operation
- Measure on multimeter between Vref pin and GND

**Pinout**:
- STEP, DIR, EN to Pico GPIO (see `docs/04_hardware_setup.md`)
- VMOT, GND to 12V power supply

**Where to buy**: 
- Robocraze, IndiaStack, SRI Electronics

---

### 4. AS5600 Absolute Encoder (~₹100)

**What it is**: 12-bit I²C magnetic angle sensor

**Why it**: 
- Absolute positioning (no calibration loss on power-cycle)
- I²C interface (easy Pico integration)
- 0.088° resolution (4096 counts/rev)
- Contactless (no wear)

**Installation**:
- Position magnet on pendulum shaft
- Sensor to opposite side of housing
- I²C pull-ups (4.7 kΩ) may be needed if long wires

**Calibration**:
- Record raw count when pendulum is exactly vertical
- Update `ZERO_RAW` in firmware (see `firmware/test_encoder.py`)

**Where to buy**: 
- Robocraze, AliExpress, Adafruit (international)

---

### 5. 12V Power Supply (~₹200)

**What it is**: AC-DC regulated adapter, 12V @ ≥1A

**Why it**: 
- NEMA 17 motor rated 12V
- A4988 input range 8V–35V (12V safe middle ground)
- Regulated (smooth operation, stable encoder readings)

**Critical spec**: 
- **Minimum 1A output** (motor draws 1.7A peak, but practical average ~0.8A during balancing)
- Decoupling capacitor (100µF, 25V) on VMOT for back-EMF spike protection

**Where to buy**: 
- Local electronics shop (cheapest, no shipping)
- Amazon India, Flipkart

**Alternative**:
- Lab-grade bench supply (if available)

---

### 6. USB Data Cable (~₹300)

**What it is**: USB-C to USB-A for Pico programming

**Why it**: 
- Pico has USB-C
- Powers Pico during development
- Necessary for `mpremote` serial communication

**Note**: Must be **data cable** (not charge-only). Test if unsure.

**Where to buy**: 
- Local mobile store, Amazon

---

### 7. Jumper Wires & Breadboard (~₹500)

**What it is**: Prototyping wiring and mini-breadboard

**Why it**: 
- For A4988 ↔ Pico connections (no soldering required)
- Testing and debugging
- Reversible (easy to reconfigure)

**Recommended**: 
- 1× mini breadboard (₹150)
- 1× pack M-M jumper wires 20cm (₹80)
- 1× pack M-F jumper wires (₹100)

**Alternative**: Solder directly if you're confident (saves ₹400, but less reversible).

---

### 8. 3D Printed Structural Components (~₹900)

**What it is**: Mechanical housing for pendulum and arm

**Why it**: 
- Motor mount bracket
- Arm support beam (7 cm length)
- Pendulum shaft and bob
- Cable management clips

**Material**: PLA (standard, low cost)

**Print parameters**:
- Layer height: 0.2 mm
- Infill: 20% (sufficient for low-speed balancing)
- Print time: ~12-14 hours total

**Where to get**:
- Local college makerspace (often ₹800-1200)
- DIY Labs, Make2Learn (Bangalore, etc.)
- Online services (local print-on-demand, ~₹1000-1500 due to shipping)

**Cost optimization**:
- If you have access to a college lab, cost drops to ₹300-500 material only
- Reuse existing mechanical mounts if available

**Files**: See `hardware/stl/README.md`

---

### 9. Miscellaneous (~₹500 buffer)

- M3 screws, nuts (₹50)
- Double-sided tape (₹30)
- Prototyping tape/hot glue (₹30)
- Wastage buffer (broken prints, bad solder joints, etc.) (₹300)

---

## Assembly Checklist

### Step 1: Mechanical Assembly (2-3 hours)

- [ ] 3D print all parts successfully
- [ ] Assemble motor to arm bracket
- [ ] Attach pendulum shaft to arm tip
- [ ] Install AS5600 sensor housing
- [ ] Mount AS5600 magnet on pendulum shaft
- [ ] Ensure arm rotates freely ±60° without binding
- [ ] Verify pendulum is balanced (bob centered) when hanging

### Step 2: Electronics Assembly (1-2 hours)

- [ ] Insert Pico into breadboard
- [ ] Insert A4988 into breadboard
- [ ] Connect A4988 STEP → Pico GP2
- [ ] Connect A4988 DIR → Pico GP3
- [ ] Connect A4988 EN → Pico GP4
- [ ] Connect A4988 GND to power supply GND and Pico GND (common ground)
- [ ] Connect A4988 VMOT → 12V power supply
- [ ] Connect A4988 motor coil 1 → motor phase A
- [ ] Connect A4988 motor coil 2 → motor phase B
- [ ] Connect AS5600 SDA → Pico GP8
- [ ] Connect AS5600 SCL → Pico GP9
- [ ] Connect AS5600 GND to common GND
- [ ] Connect AS5600 VCC to 3.3V (from Pico)
- [ ] **Critical**: Add 100µF capacitor across VMOT and GND (back-EMF protection)

### Step 3: Power-Up Test (15 min)

- [ ] **DO NOT enable motor yet**
- [ ] Plug 12V adapter (motor disabled)
- [ ] Measure voltage on A4988 VMOT: should be ~12V
- [ ] Connect USB to Pico
- [ ] Run `test_i2c_scan.py` → AS5600 should respond at 0x36
- [ ] Measure Vref on A4988: set to 0.56V with potentiometer
- [ ] Run `test_encoder.py` → motor still disabled, just reads angles
- [ ] Run `test_stepper.py` → small test pulses, motor rotates gently
- [ ] If all pass: ready for `main-lin.py`

---

## Tuning for Your Hardware

After assembly, follow [`firmware/README.md`](../firmware/README.md) section "Typical Bring-up Sequence":

1. Run all 6 tests in order
2. Record `ZERO_RAW` from `test_encoder.py`
3. Flash `main-lin.py` with `ZERO_RAW` set
4. Hold pendulum upright (within ±30°)
5. Observe serial output → should balance

**Working gains for our hardware** (as of this build):
- `KP = 150.0`
- `KD = 42.0`

If your system is unstable or sluggish, see [`docs/05_tuning_guide.md`](../docs/05_tuning_guide.md) for adjustment procedure.

---

## Troubleshooting During Assembly

| Problem | Symptom | Fix |
|---|---|-----|
| Motor won't turn | No motion on test | Check motor coil wires, verify Vref set correctly |
| Sensor not detected | I²C scan fails | Check SDA/SCL wiring, verify 3.3V on sensor |
| Erratic motion | Jittering, random steps | Check cable routing (away from motor), add ferrite clamp |
| High current draw | Power supply shuts off | Reduce current limit on A4988 (Vref down), check for mechanical binding |
| Pendulum swings wildly | Unstable in first tests | Reduce KP by 50%, increase KD, verify ZERO_RAW is correct |

---

## Procurement Timeline

| Component | Lead Time | Availability |
|---|---|---|
| Pico, A4988, Stepper, AS5600 | 2-3 days | Local (Robocraze, IndiaStack) |
| Power supply | Same day | Local electronics shop |
| USB cable | Same day | Local mobile store |
| Jumper wires, breadboard | 1-2 days | Local or online |
| 3D printing | 1-2 days | College makerspace |
| **Total** | **3-5 days** | If sourcing locally |

---

## Quality Checklist Before Powering Up

- [ ] All solder joints shiny (if soldered)
- [ ] No loose wires touching unexpectedly
- [ ] Motor coil impedance ~10Ω per phase (quick check with multimeter)
- [ ] Decoupling capacitor installed
- [ ] Common ground between all subsystems
- [ ] Pico USB cable is data cable (test with known device first)
- [ ] Mechanical: arm rotates smoothly, no grinding

---

## Cost Reduction Tips

**If building multiple units**:
- Buy motors in bulk: ₹500 per unit (vs ₹600 single)
- 3D printing material cost drops by 30% (printer amortization)
- USB cables (reuse from existing devices)

**If you have lab access**:
- Power supply: use bench supply instead of adapter (₹0)
- 3D printing: use college printer (₹200-300 material only)
- Jumper wires: scrap from old projects
- **Adjusted cost: ₹2000-2500**

**If you source internationally** (AliExpress, longer lead):
- Motor, driver, sensor cost ~40-50% less
- But shipping + delays (2-3 weeks)
- Worthwhile if building many units

---

## Next Steps

1. Gather parts using the BOM above
2. Print 3D parts (allow 12-14 hours)
3. Follow Assembly Checklist
4. Run test suite (`make test`)
5. Flash controller (`make main linear`)
6. Enjoy balanced pendulum! 🎉

For detailed firmware instructions, see [`firmware/README.md`](../firmware/README.md).

For theory, see [`docs/01_physics.md`](../docs/01_physics.md) and [`docs/02_control_design.md`](../docs/02_control_design.md).

---

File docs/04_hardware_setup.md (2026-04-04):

# Hardware Setup

## 1. Component List

| Component | Part Number | Qty | Notes |
|---|---|-----|---|
| Microcontroller | Raspberry Pi Pico | 1 | RP2040, MicroPython |
| Stepper motor | 17HS4401S NEMA 17 | 1 | 1.0 A/phase, 0.44 N·m, 1.8°/step |
| Motor driver | A4988 breakout | 1 | Verify sense resistor value |
| Angle encoder | AS5600 breakout | 1 | 12-bit magnetic, I²C |
| Magnet | 6 mm diametric disc | 1 | Neodymium, for AS5600 |
| Power supply | 12V DC, ≥ 2A | 1 | For motor rail |
| Decoupling cap | 100 µF 25V electrolytic | 1 | **Critical** — VMOT protection |
| Pull-up resistors | 4.7 kΩ | 2 | I²C SDA + SCL lines |
| Wiring | 22 AWG stranded | — | Use for VMOT/GND; 26 AWG for signals |

---

## 2. A4988 Current Calibration — Do This Before Connecting the Motor

**This is the most critical setup step.** Incorrect current causes either motor stall (too low) or motor overheating and driver destruction (too high).

### Formula

$$V_{ref} = I_{limit} \times 8 \times R_s$$

Where R_s is the current sense resistor on the A4988 board. Most breakout boards use **R_s = 0.100 Ω**. Verify by reading the resistor markings near the motor output pins:
- Marked **R100** → 0.100 Ω
- Marked **R050** → 0.050 Ω

### Target current

The 17HS4401S is rated at 1.0 A/phase. We run at **70% = 0.7 A** for a balance between torque and heat.

```
Vref = 0.7 × 8 × 0.100 = 0.56 V    (for R_s = 0.100 Ω)
Vref = 0.7 × 8 × 0.050 = 0.28 V    (for R_s = 0.050 Ω)
```

### Calibration Procedure

1. **Motor disconnected.** Do not connect motor during calibration.
2. Apply 12 V to VMOT and GND on A4988.
3. Apply 3.3 V to VDD and GND on A4988 (from Pico or bench supply).
4. Do not send any STEP pulses.
5. Place multimeter probes: **red on trimmer wiper centre**, **black on GND**.
6. Adjust trimmer until reading matches target Vref.
7. Connect motor after calibration is confirmed.

> ⚠️ The Vref shifts when the motor is connected. Always calibrate motor-disconnected, then connect the motor.

---

## 3. Pin Connections

### A4988 ↔ RPi Pico

| Signal | Pico GPIO | A4988 Pin | Notes |
|---|---|---|---|
| STEP | GP2 | STEP | One pulse = one microstep |
| DIR | GP3 | DIR | HIGH = CW, LOW = CCW |
| ENABLE | GP4 | ENABLE | **Active LOW** — drive LOW to enable |
| MS1 | — | MS1 | Tie to 3.3V (HIGH) |
| MS2 | — | MS2 | Tie to 3.3V (HIGH) |
| MS3 | — | MS3 | Tie to GND (LOW) |
| VDD | 3V3 (pin 36) | VDD | A4988 logic supply (3.0–5.5V) |
| GND | GND | GND | Common ground — critical |

MS1/MS2/MS3 are hard-wired for **1/8 microstepping** (1600 steps/rev). No GPIO needed.

**Microstepping truth table:**

| MS1 | MS2 | MS3 | Mode |
|-----|-----|-----|---|
| L | L | L | Full step |
| H | L | L | 1/2 step |
| L | H | L | 1/4 step |
| **H** | **H** | **L** | **1/8 step ← use this** |
| H | H | H | 1/16 step |

### AS5600 ↔ RPi Pico

| Signal | Pico GPIO | AS5600 Pin | Notes |
|---|---|---|---|
| SDA | GP8 | SDA | I²C0 data — add 4.7 kΩ pull-up to 3.3V |
| SCL | GP9 | SCL | I²C0 clock — add 4.7 kΩ pull-up to 3.3V |
| VCC | 3V3 (pin 36) | VCC | |
| GND | GND | GND | |

> Most AS5600 breakout boards include onboard pull-ups. Verify before adding external ones — double pull-ups are fine but if the board has 2.2 kΩ, you do not need to add 4.7 kΩ.

### 17HS4401S Motor ↔ A4988

| Motor wire | Coil | A4988 pin |
|---|---|---|
| Black | A+ | 1A |
| Green | A− | 1B |
| Red | B+ | 2A |
| Blue | B− | 2B |

> If the motor spins in the wrong direction, swap either the A pair (Black ↔ Green) **or** the B pair (Red ↔ Blue) — not both simultaneously.

---

## 4. Full Wiring Schematic

```
╔═══════════════════════════════════════════════════════════════╗
║  POWER                                                        ║
║  12V PSU (+) ──────────────────────┬─────── VMOT (A4988)     ║
║                                  [100µF]                      ║
║  12V PSU (−) / GND ────────────────┴─────── GND  (A4988)     ║
║                    └──────────────────────── GND  (Pico)      ║
║                    └──────────────────────── GND  (AS5600)    ║
╠═══════════════════════════════════════════════════════════════╣
║  PICO ↔ A4988                                                 ║
║  GP2  ──────────────────────────────────── STEP               ║
║  GP3  ──────────────────────────────────── DIR                ║
║  GP4  ──────────────────────────────────── ENABLE (active LOW)║
║  3V3  ──────────────────────────────────── VDD                ║
║  3V3  ──────────────────────────────────── MS1                ║
║  3V3  ──────────────────────────────────── MS2                ║
║  GND  ──────────────────────────────────── MS3                ║
╠═══════════════════════════════════════════════════════════════╣
║  PICO ↔ AS5600                                                ║
║  GP8  ──[4.7kΩ→3V3]────────────────────── SDA                ║
║  GP9  ──[4.7kΩ→3V3]────────────────────── SCL                ║
║  3V3  ──────────────────────────────────── VCC                ║
╠═══════════════════════════════════════════════════════════════╣
║  A4988 ↔ MOTOR                                                ║
║  1A ─── Black (A+)     2A ─── Red  (B+)                      ║
║  1B ─── Green (A−)     2B ─── Blue (B−)                      ║
╠═══════════════════════════════════════════════════════════════╣
║  PICO POWER                                                   ║
║  VSYS (pin 39) ─── USB during development                     ║
╚═══════════════════════════════════════════════════════════════╝
```

---

## 5. AS5600 Magnet Installation

- Use a **6 mm diametrically magnetised disc magnet** (neodymium).
- Mount magnet **on the pendulum pivot shaft**, centred on the AS5600 chip axis.
- Air gap: **0.5–3 mm** (verify with MD bit in status register — see `test_encoder.py`).
- The magnet rotates **with the pendulum**; the AS5600 PCB is **fixed** to the arm.
- Centre the magnet carefully — off-centre mounting causes angle-dependent error.

---

## 6. Physical Assembly Order

1. Mount stepper motor to base plate.
2. Attach arm to motor shaft. Tighten set screw — any shaft slop corrupts step count.
3. Mount pendulum pivot bearing at arm tip.
4. Thread AS5600 wires through or along the arm **before** attaching pendulum rod.
5. Attach pendulum rod to pivot.
6. Glue or press-fit magnet onto pendulum pivot shaft, centred and flush.
7. Mount AS5600 PCB on arm, facing magnet, ~1–2 mm gap.
8. Leave a **service loop** of slack wire at the pivot — do not run wires taut.
9. Mount Pico and A4988 on the fixed base (they do not rotate).
10. Add JST connector at arm-base wire junction for easy disassembly.
11. Install 100 µF capacitor close to A4988 VMOT/GND pins.

---

## 7. Pre-Power Checklist

- [ ] Vref set to 0.56 V (motor disconnected during measurement)
- [ ] Motor connected to A4988 after calibration
- [ ] 100 µF cap across VMOT/GND, physically close to A4988
- [ ] All grounds common (Pico GND, A4988 GND, 12V PSU GND)
- [ ] AS5600 pull-ups present on SDA and SCL
- [ ] Magnet centred, MD status bit = 1 (verified in software test)
- [ ] MS1 = H, MS2 = H, MS3 = L (1/8 step confirmed)
- [ ] ENABLE pin wired and LOW = enable understood in firmware
- [ ] Wire service loop present at pivot, no taut wires

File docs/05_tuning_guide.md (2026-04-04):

# Gain Tuning Guide

Run all firmware tests in `firmware/` before starting this procedure. Do not attempt tuning without first verifying every subsystem independently.

---

## Starting Gains

Open `firmware/main.py` and set:

```python
KP = 940.0
KD = 42.0
K_CENTER = 1.5
ALPHA_EMA = 0.20
```

These correspond to ωc = 2.5 × ωₙ — conservative, slow, but safe to start.

---

## Round 1 — Verify Direction

Power up with pendulum held upright. Watch the serial output. Release the pendulum with **zero initial disturbance** (as straight up as you can hold it).

**The motor should immediately respond in the correct direction.** If the arm consistently drives the pendulum *away* from vertical (making it fall faster), you have a sign error. Fix by either:

- Negating `phi` in `read_phi()` — swap the sign convention, or
- Swapping `DIR_PIN` HIGH/LOW logic in `fire_steps()`

Do not proceed until the direction is correct.

---

## Round 2 — Find the Proportional Boundary

With correct direction confirmed, increase Kp in steps of 200:

```
940 → 1140 → 1340 → 1540 → 1758 → ...
```

After each increase, hold the pendulum up, release, and observe. You are looking for the transition from:

- **Too low Kp:** pendulum drifts slowly to one side and falls. Motor responds but not fast enough.
- **About right:** pendulum resists small disturbances and recovers.
- **Too high Kp:** arm oscillates rapidly left-right at high frequency (the motor buzzes). Back off 20%.

Note the Kp where oscillation begins. Your operating Kp should be **80% of that value**.

---

## Round 3 — Add Derivative Damping

With Kp set, increase Kd from 42 upward in steps of 5:

```
42 → 47 → 52 → 57 → 62 → ...
```

Signs of too-low Kd:
- Pendulum rocks back and forth multiple times before settling (underdamped)
- Sustained oscillation that does not decay

Signs of too-high Kd (or noisy velocity estimate):
- High-frequency arm chatter audible as buzzing, even when pendulum is nearly vertical
- Motor makes grinding noise in rapid direction alternation

If you get chatter before reaching good damping, reduce `ALPHA_EMA` to 0.10–0.15 (more smoothing on velocity) and try again. Alternatively, increase `N_DIFF` to 4 or 5.

---

## Round 4 — Test Disturbance Rejection

With Kp and Kd set, apply a deliberate tap to the pendulum (~5° disturbance). It should:

- Respond within one or two control cycles (4–8 ms)
- Correct back to vertical within ~0.5 s
- Not overshoot more than ~2–3° in the opposite direction

If recovery is sluggish, increase Kp by 10% and repeat. If overshoot is excessive, increase Kd by 5 and repeat.

---

## Round 5 — Arm Centering

Deliberately push the arm to ~30° from centre while the pendulum is being balanced. Release. The arm should:

- Slowly drift back toward centre over several seconds
- Not cause the pendulum to fall during centering

If balance breaks during arm centering, reduce K_CENTER (try 0.8–1.0). If the arm barely returns, increase K_CENTER toward 2.5.

---

## Round 6 — Nominal Gains

Once the conservative gains work well, try the nominal set:

```python
KP = 1858.0
KD = 59.4
```

This corresponds to ωc = 3.5 × ωₙ. Repeat Rounds 2–5 with these values. The response will be crisper and disturbance rejection faster. Adjust from these values based on what you observe.

---

## Interpreting Serial Output

```
[ACTIVE    ] φ=+0.34°  φ̇=  -2.1°/s  θ=+12.3°  step_rate=  +87  u=  -412
```

| Field | Meaning | Good value at balance |
|---|---|---|
| φ | pendulum angle | < ±2° |
| φ̇ | pendulum velocity | < ±20 °/s |
| θ | arm angle | drifting slowly, < ±40° |
| step_rate | current arm speed | low magnitude during balance |
| u | control command (rad/s²) | fluctuating, not saturating |

If `u` is constantly at ±600 (the clamp), the gains are too high or the pendulum is too far from vertical. If `u` is near zero while the pendulum is visibly tilted, the gains are too low.

---

## Final Parameters (Fill In After Successful Run)

```python
# Record your tuned values here
KP         = ___
KD         = ___
K_CENTER   = ___
ALPHA_EMA  = ___
N_DIFF     = ___
ZERO_RAW   = ___   # from test_encoder.py
```

---

## Troubleshooting

| Symptom | Likely cause | Fix |
|---|---|-----|
| Motor doesn't move at all | ENABLE pin not driven LOW | Check GP4 is pulled LOW in code |
| Motor moves but pendulum falls instantly | Direction wrong | Negate phi or swap DIR logic |
| Loud buzzing, arm vibrating | Kd too high or velocity too noisy | Reduce Kd, lower ALPHA_EMA |
| Pendulum drifts slowly | Kp too low | Increase Kp by 200 |
| Arm hits limit repeatedly | K_center too low | Increase K_center |
| Arm hits limit and balance breaks | K_center too high fighting PD | Reduce K_center |
| AS5600 reads jump erratically | Magnet not centred or gap too large | Adjust magnet position |
| Step count drifts, arm position wrong | Step loss at high speed | Reduce MAX_STEP_RATE to 600 |

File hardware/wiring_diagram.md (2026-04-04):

# Wiring Diagram

Full wiring reference for the Furuta Pendulum. See [`../docs/04_hardware_setup.md`](../docs/04_hardware_setup.md) for the complete setup procedure including current calibration.

---

## Pin Reference

### RPi Pico → A4988

| Pico Pin | GPIO | A4988 | Notes |
|---|---|---|---|
| Pin 4 | GP2 | STEP | Step pulse |
| Pin 5 | GP3 | DIR | Direction |
| Pin 6 | GP4 | ENABLE | Active LOW |
| Pin 36 | 3V3 | VDD | Logic supply |
| Pin 36 | 3V3 | MS1 | Hard-wired HIGH |
| Pin 36 | 3V3 | MS2 | Hard-wired HIGH |
| Any GND | GND | MS3 | Hard-wired LOW → 1/8 step |
| Any GND | GND | GND | Common ground |

### RPi Pico → AS5600

| Pico Pin | GPIO | AS5600 | Notes |
|---|---|---|---|
| Pin 11 | GP8 | SDA | I²C0, 4.7 kΩ pull-up |
| Pin 12 | GP9 | SCL | I²C0, 4.7 kΩ pull-up |
| Pin 36 | 3V3 | VCC | |
| Any GND | GND | GND | |

### A4988 → 17HS4401S Motor

| A4988 | Motor wire | Coil |
|---|---|---|
| 1A | Black | A+ |
| 1B | Green | A− |
| 2A | Red | B+ |
| 2B | Blue | B− |

### Power

| From | To | Note |
|---|-----|---|
| 12V PSU (+) | A4988 VMOT | Through 100 µF cap to GND |
| 12V PSU (−) | A4988 GND, Pico GND | All grounds common |
| USB | Pico VSYS | Development power |

---

## Full Schematic

```
 12V ──┬──────────────────────────────────── VMOT (A4988)
       │
     [100µF 25V]    ← place physically close to A4988
       │
 GND ──┴──────────────────── A4988 GND ── Pico GND ── AS5600 GND

 RPi Pico                    A4988
 ┌──────────────┐            ┌───────────────────┐
 │ GP2  ────────┼────────────┤ STEP              │
 │ GP3  ────────┼────────────┤ DIR               │
 │ GP4  ────────┼────────────┤ ENABLE (act. LOW) │
 │ 3V3  ────────┼────────────┤ VDD               │
 │ 3V3  ────────┼────────────┤ MS1 (HIGH)        │ 1/8 step
 │ 3V3  ────────┼────────────┤ MS2 (HIGH)        │
 │ GND  ────────┼────────────┤ MS3 (LOW)         │
 │              │            │                   │
 │              │            │ 1A ──── BLK (A+)  │──► Motor
 │              │            │ 1B ──── GRN (A−)  │──► Motor
 │              │            │ 2A ──── RED (B+)  │──► Motor
 │              │            │ 2B ──── BLU (B−)  │──► Motor
 │              │            │ [Vref trimmer]    │
 │              │            │  set to 0.56V     │
 │              │            └───────────────────┘
 │ GP8 (SDA) ───┼──[4.7kΩ]──3V3
 │         └────┼────────────── SDA (AS5600)
 │ GP9 (SCL) ───┼──[4.7kΩ]──3V3
 │         └────┼────────────── SCL (AS5600)
 │ 3V3  ────────┼────────────── VCC (AS5600)
 │              │
 │ VSYS ────────┼────────────── USB
 └──────────────┘
```

---

## Important Notes

- The 100 µF capacitor **must** be placed physically close to the A4988 VMOT and GND pins. Motor deceleration generates back-EMF spikes that destroy the A4988 without this capacitor.
- Use 22 AWG or heavier wire for VMOT and GND power runs. Thin wire adds resistance that causes erratic motor behaviour under load.
- Keep I²C lines (SDA/SCL) physically away from the STEP pulse line. If they must cross, cross at 90°.
- AS5600 wires on the rotating arm: leave a **service loop** of slack at the pivot. Never route taut.

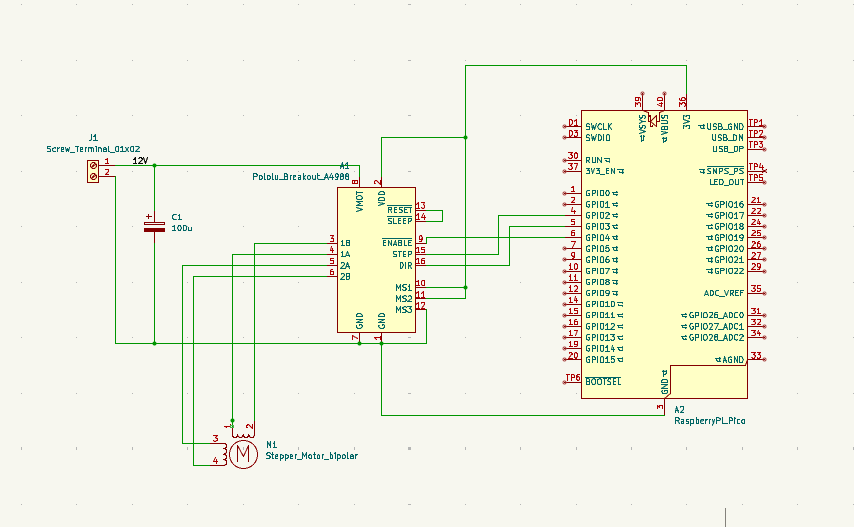
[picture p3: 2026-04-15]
hardware/wiring-motor.png

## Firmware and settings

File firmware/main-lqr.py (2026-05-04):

# main-lqr.py
# Furuta Pendulum — LQR Balance Controller
# Hardware: RPi Pico + 17HS4401S + A4988 + AS5600
#
# BEFORE RUNNING:
#   1. Complete all 6 tests in firmware/test_*.py
#   2. Set ZERO_RAW to the value from test_encoder.py
#   3. Start with CONSERVATIVE gains (default below)
#   4. Follow tuning procedure in docs/05_tuning_guide.md
#   5. Always hold pendulum upright before the script activates

from machine import Pin, I2C
import time, math

# ─────────────────────────────────────────────
#  HARDWARE PINS
# ─────────────────────────────────────────────
STEP_PIN = Pin(2, Pin.OUT)
DIR_PIN  = Pin(3, Pin.OUT)
EN_PIN   = Pin(4, Pin.OUT)
i2c = I2C(1, sda=Pin(14), scl=Pin(15), freq=400_000)

# ─────────────────────────────────────────────
#  SYSTEM CONSTANTS
# ─────────────────────────────────────────────
AS5600_ADDR   = 0x36
STEPS_PER_REV = 1600           # 200 base × 8 microsteps (1/8 step)
RAD_PER_STEP  = 2*math.pi / STEPS_PER_REV
RAD_PER_COUNT = 2*math.pi / 4096

# ─────────────────────────────────────────────
#  CALIBRATION  ← set from test_encoder.py
# ─────────────────────────────────────────────
ZERO_RAW = 1750    # raw AS5600 count when pendulum is exactly upright

# ─────────────────────────────────────────────
#  LQR CONTROL GAINS
#
#  State: x = [φ, φ̇, θ, θ̇]
#  Control: u = -K @ x = -[k1, k2, k3, k4] @ [φ, φ̇, θ, θ̇]
#
#  LQR gain sets — uncomment one to select:
#  (Computed with Q=diag(q1, q2, q3, q4), R=r)
# ─────────────────────────────────────────────

# Conservative: Q=diag(100, 10, 10, 1), R=0.1
K_LQR = [150.0, 42.0, 6.0, 2.0]  # [k_phi, k_phi_dot, k_theta, k_theta_dot]

# Nominal: Q=diag(150, 20, 15, 2), R=0.1
# K_LQR = [200.0, 50.0, 10.0, 3.0]

# Aggressive: Q=diag(200, 30, 20, 3), R=0.05
# K_LQR = [250.0, 60.0, 15.0, 4.0]

K_CENTER = 6    # arm centering gain [rad/s² per rad of arm displacement]

# ─────────────────────────────────────────────
#  CONTROLLER PARAMETERS
# ─────────────────────────────────────────────
DT_S           = 0.002          # 500 Hz control loop (seconds)
DT_US          = 2000           # same in microseconds

ALPHA_EMA      = 0.8           # velocity EMA smoothing (tune from test_velocity.py)
N_DIFF         = 3              # finite difference window (samples)

ALPHA_MAX      = 600.0          # max arm angular accel command [rad/s²]
MAX_STEP_RATE  = 8000.0          # max step rate [steps/s] — safe torque zone
MAX_STEP_ACCEL = 5120000.0/8         # step rate ramp limit [steps/s²]

UNWIND_STEP_RATE   = 7000.0        # [steps/s] fast unwind rate in LIMIT_HIT
THETA_ZERO_TOL_RAD = math.radians(2)  # [rad] consider arm "back to zero" within this

THETA_SOFT_RAD = math.radians(90)   # arm soft limit: centering ramps up
THETA_HARD_RAD = math.radians(120)   # arm hard stop: motor disabled
PHI_CUTOFF_RAD = math.radians(75)   # pendulum fall threshold → RECOVERING
PHI_ACTIVE_RAD = math.radians(30)    # must be within this to activate/recover

# ─────────────────────────────────────────────
#  STATE MACHINE
# ─────────────────────────────────────────────
IDLE       = 0    # motor off, waiting for upright
ACTIVE     = 1    # LQR control running
RECOVERING = 2    # pendulum fell >15°, waiting for manual reset
LIMIT_HIT  = 3    # arm hit cable wrap limit
FAULT      = 4    # sensor error

STATE_NAMES = {0:"IDLE", 1:"ACTIVE", 2:"RECOVERING", 3:"LIMIT_HIT", 4:"FAULT"}

# ─────────────────────────────────────────────
#  RUNTIME STATE
# ─────────────────────────────────────────────
state          = IDLE
step_rate      = 0.0     # current step rate [steps/s, signed]
step_count     = 0       # arm position [steps from activation zero]
step_accum     = 0.0     # fractional step accumulator

phi_history    = [0.0] * (N_DIFF + 2)
phi_dot_filt   = 0.0
idle_timer_ms  = 0.0

# ─────────────────────────────────────────────
#  HARDWARE HELPERS
# ─────────────────────────────────────────────
def motor_enable():
    EN_PIN.value(0)

def motor_disable():
    global step_rate
    EN_PIN.value(1)
    step_rate = 0.0

def read_raw_count() -> int:
    """Read raw AS5600 count (0..4095)."""
    data = i2c.readfrom_mem(AS5600_ADDR, 0x0C, 2)
    return ((data[0] & 0x0F) << 8) | data[1]

def read_phi() -> float:
    """Read AS5600 and return pendulum angle in radians (0 = upright)."""
    raw   = read_raw_count()
    delta = raw - ZERO_RAW
    if delta >  2048: delta -= 4096
    if delta < -2048: delta += 4096
    return delta * RAD_PER_COUNT

def check_magnet() -> bool:
    # status = i2c.readfrom_mem(AS5600_ADDR, 0x0B, 1)[0]
    # return bool(status & 0x08)
    return True

def fire_steps(n: int):
    """Fire abs(n) step pulses. Sign of n sets direction."""
    global step_count
    if n == 0:
        return
    DIR_PIN.value(0 if n > 0 else 1)
    time.sleep_us(2)
    for _ in range(abs(n)):
        STEP_PIN.value(1)
        time.sleep_us(2)
        STEP_PIN.value(0)
        time.sleep_us(2)
    step_count += n

# ─────────────────────────────────────────────
#  STEP RATE CONTROLLER
# ─────────────────────────────────────────────
def update_stepper(target_rate: float, dt: float):
    """
    Ramp step_rate toward target_rate, limited by MAX_STEP_ACCEL.
    Fire accumulated steps. Returns steps fired this cycle.
    """
    global step_rate, step_accum

    max_delta = MAX_STEP_ACCEL * dt
    error     = target_rate - step_rate
    if abs(error) <= max_delta:
        step_rate = target_rate
    else:
        step_rate += math.copysign(max_delta, error)

    step_rate = max(-MAX_STEP_RATE, min(MAX_STEP_RATE, step_rate))

    step_accum += step_rate * dt
    steps = int(step_accum)
    step_accum -= steps

    fire_steps(steps)
    return steps

# ─────────────────────────────────────────────
#  CENTERING RAMP
# ─────────────────────────────────────────────
def centering_ramp(theta: float) -> float:
    """
    Returns centering gain multiplier.
    1× within soft limit, ramps 1→6× toward hard limit.
    """
    abs_theta = abs(theta)
    if abs_theta <= THETA_SOFT_RAD:
        return 1.0
    elif abs_theta <= THETA_HARD_RAD:
        frac = (abs_theta - THETA_SOFT_RAD) / (THETA_HARD_RAD - THETA_SOFT_RAD)
        return 1.0 + 5.0 * frac
    else:
        return 0.0   # past hard limit — handled by state machine

# ─────────────────────────────────────────────
#  CONTROL LAW (LQR)
# ─────────────────────────────────────────────
def compute_control(phi: float, phi_dot: float, theta: float, theta_dot: float) -> float:
    """
    Returns commanded arm angular acceleration [rad/s²].
    Implements LQR state-feedback control + arm centering with soft-limit ramp.
    
    State: x = [φ, φ̇, θ, θ̇]
    Control: u_lqr = -K @ x
    Total: u = u_lqr + u_center
    """
    # LQR state-feedback term
    u_lqr = -(K_LQR[0] * phi + K_LQR[1] * phi_dot + K_LQR[2] * theta + K_LQR[3] * theta_dot)
    
    # Centering term (same as before) — brings arm to center with virtual spring
    u_center = -K_CENTER * centering_ramp(theta) * theta
    
    # Total command
    u_total = u_lqr + u_center
    
    return max(-ALPHA_MAX, min(ALPHA_MAX, u_total))

# ─────────────────────────────────────────────
#  MAIN LOOP
# ─────────────────────────────────────────────
def main():
    global state, phi_history, phi_dot_filt, idle_timer_ms, step_count, ZERO_RAW, step_rate, step_accum

    print("=" * 50)
    print("  Furuta Pendulum — LQR Balance Controller")
    print("  IIT Kharagpur — EECE Design Lab")
    print("=" * 50)
    print(f"  K_LQR={K_LQR}")
    print(f"  K_center={K_CENTER}")
    print(f"  Loop: {int(1/DT_S)} Hz,  Max step rate: {MAX_STEP_RATE} steps/s")
    print()

    if not check_magnet():
        print("FAULT: AS5600 magnet not detected.")
        print("       Check magnet gap and orientation. Exiting.")
        state = FAULT
        return

    # ── Startup zero calibration ─────────────────
    # Ask user to hold pendulum upright, then capture encoder count as ZERO_RAW.
    print("Hold the pendulum exactly upright, then press Enter to calibrate zero.")
    try:
        _ = input("Ready? ")
    except Exception:
        # If running in a non-interactive environment, keep the configured ZERO_RAW.
        print("(No stdin available — using configured ZERO_RAW.)")
    else:
        try:
            samples = 25
            sum_sin = 0.0
            sum_cos = 0.0
            for _ in range(samples):
                raw = read_raw_count()
                ang = raw * (2 * math.pi / 4096)
                sum_sin += math.sin(ang)
                sum_cos += math.cos(ang)
                time.sleep_ms(5)

            mean_ang = math.atan2(sum_sin, sum_cos)
            if mean_ang < 0:
                mean_ang += 2 * math.pi
            ZERO_RAW = int(round(mean_ang * 4096 / (2 * math.pi))) % 4096
            print(f"Calibrated ZERO_RAW = {ZERO_RAW}")
        except Exception:
            state = FAULT
            motor_disable()
            print("FAULT: I2C read error during calibration. Stopping.")
            return

    phi_now    = read_phi()
    phi_history = [phi_now] * (N_DIFF + 2)

    motor_disable()
    print(f"State: IDLE")
    print(f"Hold pendulum upright (within {math.degrees(PHI_ACTIVE_RAD):.0f}°) to activate.\n")

    loop_count  = 0
    print_every = 100   # status print every 100 loops = 200 ms

    while True:
        t_start = time.ticks_us()

        # ── 1. READ SENSOR ──────────────────────────
        try:
            phi = read_phi()
        except Exception:
            state = FAULT
            motor_disable()
            print("FAULT: I2C read error. Stopping.")
            break

        # ── 2. VELOCITY ESTIMATE ────────────────────
        phi_history    = [phi] + phi_history[:-1]
        phi_dot_raw    = (phi_history[0] - phi_history[N_DIFF]) / (N_DIFF * DT_S)
        phi_dot_filt   = ALPHA_EMA * phi_dot_raw + (1 - ALPHA_EMA) * phi_dot_filt

        # ── 3. ARM ANGLE ────────────────────────────
        theta = step_count * RAD_PER_STEP

        # ── 4. STATE MACHINE ────────────────────────
        if state == IDLE:
            motor_disable()
            if abs(phi) < PHI_ACTIVE_RAD:
                idle_timer_ms += DT_S * 1000
                if idle_timer_ms >= 500:
                    state         = ACTIVE
                    step_count    = 0      # zero arm position on activation
                    step_rate     = 0.0
                    step_accum    = 0.0
                    # phi_now       = read_phi()
                    # phi_history   = [phi_now] * (N_DIFF + 2)
                    # phi_dot_filt  = 0.0
                    idle_timer_ms = 0.0
                    motor_enable()
                    print(">>> ACTIVE — balancing")
            else:
                idle_timer_ms = 0

        elif state == ACTIVE:
            if abs(phi) > PHI_CUTOFF_RAD:
                state = RECOVERING
                motor_disable()
                idle_timer_ms = 0.0
                print(f">>> RECOVERING — φ = {math.degrees(phi):.1f}°  (> 75°)")
            elif abs(theta) > THETA_HARD_RAD:
                state = LIMIT_HIT
                idle_timer_ms = 0.0
                # Keep motor enabled to actively unwind back toward zero.
                step_rate  = 0.0
                step_accum = 0.0
                print(f">>> LIMIT_HIT — arm at {math.degrees(theta):.1f}° (unwinding to 0°)")
            else:
                # Estimate arm angular velocity from step rate
                theta_dot = step_rate * RAD_PER_STEP / DT_S
                
                # LQR control with full state feedback
                u = compute_control(phi, phi_dot_filt, theta, theta_dot)

                # u [rad/s²] → integrate to target step rate
                # target_step_rate = current_step_rate + u·dt·(steps/rad)
                target_step_rate = (step_rate + u * DT_S * STEPS_PER_REV / (2 * math.pi))
                update_stepper(target_step_rate, DT_S)

        elif state == RECOVERING:
            motor_disable()
            if abs(phi) < PHI_ACTIVE_RAD:
                idle_timer_ms += DT_S * 1000
                if idle_timer_ms >= 500:
                    state        = ACTIVE
                    step_count   = 0
                    step_rate     = 0.0
                    step_accum    = 0.0
                    # phi_now       = read_phi()
                    # phi_history   = [phi_now] * (N_DIFF + 2)
                    # phi_dot_filt  = 0.0
                    idle_timer_ms = 0.0
                    motor_enable()
                    print(">>> ACTIVE — recovered")
            else:
                idle_timer_ms = 0

        elif state == LIMIT_HIT:
                    # We hit the wire limit. The pendulum WILL fall. 
                    # Ignore the angle, drive to 0 safely, then go to RECOVERING.
                    motor_enable()

                    if abs(theta) <= THETA_ZERO_TOL_RAD:
                        # Arm is centered. Stop motor and wait for human to stand pendulum up.
                        step_count   = 0
                        step_rate    = 0.0
                        step_accum   = 0.0
                        idle_timer_ms = 0.0
                        state = RECOVERING
                        print(">>> UNWIND COMPLETE — waiting for human reset")
                    else:
                        # Drive back toward 0. Use 2000 steps/s (7000 is too violent for a hanging pendulum)
                        target_step_rate = math.copysign(2000.0, -theta)
                        update_stepper(target_step_rate, DT_S)

        elif state == FAULT:
            motor_disable()
            break

        # ── 5. STATUS OUTPUT ────────────────────────
        loop_count += 1
        if loop_count % print_every == 0:
            if state == ACTIVE:
                theta_dot_display = step_rate * RAD_PER_STEP / DT_S
                u_display = compute_control(phi, phi_dot_filt, theta, theta_dot_display)
            else:
                u_display = 0.0
            print(f"[{STATE_NAMES[state]:10s}] "
                  f"φ={math.degrees(phi):+6.2f}°  "
                  f"φ̇={math.degrees(phi_dot_filt):+7.1f}°/s  "
                  f"θ={math.degrees(theta):+6.1f}°  "
                  f"rate={step_rate:+6.0f}  "
                  f"u={u_display:+5.0f}")

        # ── 6. LOOP TIMING ──────────────────────────
        elapsed   = time.ticks_diff(time.ticks_us(), t_start)
        remaining = DT_US - elapsed
        if remaining > 0:
            time.sleep_us(remaining)

# ─────────────────────────────────────────────
#  ENTRY POINT
# ─────────────────────────────────────────────
if __name__ == "__main__":
    try:
        main()
    except KeyboardInterrupt:
        motor_disable()
        print("\nStopped by user. Motor disabled.")

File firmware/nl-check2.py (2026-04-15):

import math
import matplotlib.pyplot as plt

# Physics and Time
DT = 0.002           # 500 Hz
T_MAX = 3.0          # Simulate 3 seconds
STEPS = int(T_MAX / DT)
G = 9.81
L = 0.07             # 7cm arm length (from test_motor_encoder.py)

# Controller Gains (from your successful run)
KP = 190.0
KD = 42.0
K1 = 0.03            # Estimated k1

def simulate(mode: str):
    """Simulate pendulum response.

    Modes:
      - 'standard': u = KP*phi + KD*phi_dot
      - 'log_p':    u = (KP*phi)*log(|phi|/K1 + 1) + KD*phi_dot
      - 'log_pd':   u = (KP*phi + KD*phi_dot)*log(|phi|/K1 + 1)
    """
    phi = math.radians(15.0)  # Start dropped at 15 degrees
    phi_dot = 0.0

    time_log = []
    phi_log = []

    for i in range(STEPS):
        time_log.append(i * DT)
        phi_log.append(math.degrees(phi))

        # 1. Controller Math
        u_p = KP * phi
        u_d = KD * phi_dot

        if mode == "standard":
            u = u_p + u_d
        else:
            modifier = math.log((abs(phi) / K1) + 1.0)
            if mode == "log_p":
                u = (u_p * modifier) + u_d
            elif mode == "log_pd":
                u = (u_p + u_d) * modifier
            else:
                raise ValueError(f"Unknown mode: {mode}")

        u = max(-600, min(600, u))  # Clamp to ALPHA_MAX

        # 2. Physics (phi_ddot = (g/L)*sin(phi) - u)
        # Assuming the arm acceleration translates directly to pendulum base acceleration
        phi_ddot = (G / L) * math.sin(phi) - u

        # 3. Integration
        phi_dot += phi_ddot * DT
        phi += phi_dot * DT

    return time_log, phi_log

# Run simulations
t, phi_standard = simulate("standard")
_, phi_log_p = simulate("log_p")
_, phi_log_pd = simulate("log_pd")

# Plot Results (two horizontally stacked subplots)
fig, (ax1, ax2) = plt.subplots(1, 2, figsize=(14, 5), sharey=True)

ax1.plot(t, phi_standard, label="Standard PD", linewidth=2)
ax1.plot(t, phi_log_p, label=f"Log (k1={K1})", linewidth=2, linestyle="--")
ax1.axhline(0, color="black", linewidth=1)
ax1.set_title("non-linearity in p")
ax1.set_xlabel("Time (s)")
ax1.set_ylabel("Pendulum Angle (degrees)")
ax1.grid(True)
ax1.legend()

ax2.plot(t, phi_standard, label="Standard PD", linewidth=2)
ax2.plot(t, phi_log_pd, label=f"Log (k1={K1})", linewidth=2, linestyle="--")
ax2.axhline(0, color="black", linewidth=1)
ax2.set_title("full non-linearity")
ax2.set_xlabel("Time (s)")
ax2.grid(True)
ax2.legend()

plt.tight_layout()
plt.show()

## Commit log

2026-04-15 Working Setup V1
    [base.stl, pendulum_v1.stl]
2026-05-04 Revert "[UNTESTED] Organizing the folder and Adding LQR"
    This reverts commit 2c37b2a82d5ed4292647fc27c5ce173b300be01c.
    [main-lin.py, main-nl-full.py, main-nl-p.py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]
2026-06-01 Update documentation and firmware setup
    - Revise README.md to include Thonny workflow and firmware guide.
    - Add LQR control design considerations in 06_lqr_control.md.
    - Introduce Thonny Workflow Guide as a new document.
    - Create Build Guide for constructing the Furuta Pendulum.
    - Enhance firmware README with detailed setup instructions and test scripts.
    - Rename motor speed test script for clarity.
    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
